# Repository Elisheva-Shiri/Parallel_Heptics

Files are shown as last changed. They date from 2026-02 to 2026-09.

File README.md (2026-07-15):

# Parallel Heptics

Hand-tracking psychophysics experiment for studying perceived stiffness through
parallel haptic feedback. A top-view camera tracks the participant's fingers,
the optional side camera remains available for side-view/z data, and an
ESP32-driven servo cluster delivers the haptic response. Participants see and
interact with a virtual object either on screen (pygame) or in VR (Unity + Meta
Quest via Quest Link).

## Components

- **Backend** (`backend.py`) — Python orchestrator. Runs vision (MediaPipe / YOLO /
  color), the virtual object simulation, the protocol/state machine, and the
  motor controller. Records video, finger trajectories, and answers per
  experiment run.
- **Frontends** — exactly one runs at a time:
  - `frontend_pygame.py` (computer screen).
  - `frontend_unity/` (Unity 6 PCVR project for Meta Quest via Quest Link).
- **Hardware** — ESP32 with PCA9685 16-channel servo driver and 15 SG92R servos
  (5 fingers × 3 servos). Firmware in `Arduino/servo_pca9685_motors_controller/`.
- **ESP32 serial bridge** (`esp32_serial_bridge/`) — required C++ UDP-to-serial
  bridge. The backend's `MotorType.HARDWARE` path only emits UDP packets to
  `HARDWARE_PORT` (12347); the bridge is what forwards them to the ESP32 over
  serial. Without it, motor commands go nowhere.
- **Moderator control** (`moderator_control.py`) — one-shot CLI for the
  moderator to toggle interaction, finish a break, or pause the run. Subjects
  can also toggle interaction from the active frontend: press Space in pygame,
  or press a Quest controller button in Unity (excluding the Meta/system button).

The data path is:

```
Cameras → backend.py → motor commands → (UDP 12347) → esp32_bridge.exe → Serial → ESP32 → servos
                    ↘ ExperimentPacket (UDP 12346) → pygame/Unity frontend
                    ↖ ExperimentControl (TCP 12344) ← moderator_control.py / frontend
```

---

## Minimum system requirements and complete setup checklist

The project does not enforce a CPU, RAM, or disk-space threshold in code. The
computer specifications below are therefore practical lower bounds inferred
from the 640x480 camera streams, MediaPipe/OpenCV processing, video recording,
and the selected frontend. For a new computer, prefer the recommended values
rather than purchasing exactly at the minimum.

### Computer requirements

| Configuration | CPU | RAM | GPU | Free storage | Operating system |
| --- | --- | --- | --- | --- | --- |
| Minimum pygame + MediaPipe | 4-core Intel Core i5 / AMD Ryzen 5 class | 8 GB | Integrated graphics are acceptable | 10 GB plus experiment recordings | Windows 10/11 64-bit |
| Recommended non-VR experiment PC | Modern 6-core CPU | 16 GB | Integrated or entry-level discrete GPU | 20-50 GB | Windows 11 64-bit |
| Quest Link / PCVR | Intel Core i7 / AMD Ryzen 7 class | 16 GB | NVIDIA RTX 20-series or AMD RX 6000-series class | 30-50 GB | Windows 10/11 64-bit |
| Unity development | Modern Core i7 / Ryzen 7 | 16 GB minimum; 32 GB preferred | RTX 20-series or newer | 50 GB or more | Windows 11 64-bit |

Before purchasing a VR computer, verify it against Meta's current
[Windows PC requirements for Meta Horizon Link](https://www.meta.com/help/quest/articles/headsets-and-accessories/oculus-link/requirements-quest-link/).

Required computer connections:

- Two USB ports for the minimum physical setup: top camera + ESP32.
- A third USB port when the optional side camera is enabled.
- An additional USB 3 port and data-capable Link cable for wired Quest Link.
- A monitor, keyboard, and mouse. An audio output is needed when white-noise
  masking is enabled.

### Hardware requirements

The minimum visual demonstration needs only the computer, one top camera, and
the pygame frontend. It does not need the ESP32, servos, side camera, or Quest.
For an intentional software-only run, set `MOTOR_TYPE = MotorType.NONE` in
`backend.py`; the committed default is `MotorType.HARDWARE`.

The minimum physical haptic system consists of:

- One ESP32 development board.
- One PCA9685 16-channel PWM/servo driver.
- Three SG92R servos for one finger cluster. The complete five-finger system
  uses 15 servos (five clusters x three servos).
- One data-capable USB cable for the ESP32.
- A separate regulated 5-6 V servo power supply, wiring, and a common ground
  shared by the supply, PCA9685, and ESP32.
- One fixed top-view USB camera. The side-view USB camera is optional.

The firmware defines 15 motors on PCA9685 channels 0-14, ESP32 I2C pins SDA 21
and SCL 22, PCA9685 address `0x40`, 50 Hz servo PWM, and 115200-baud serial.

> **Servo power safety:** Never power all servos from the ESP32 USB connector.
> The repository does not define a power-supply rating. Size the supply for the
> measured stall current of the actual servos; approximately 5 V / 10 A or more
> is a sensible engineering provision for 15 SG92R-class servos. Add suitable
> fusing or an emergency disconnect. See Adafruit's
> [PCA9685 power and library guide](https://learn.adafruit.com/16-channel-pwm-servo-driver/using-the-adafruit-library).

Optional VR hardware:

- A Meta Quest headset supported by Meta Horizon Link and its controllers.
- A high-quality USB 3 Link cable. Wired Link is preferred over Air Link for
  repeatable experiment latency.
- A Meta account and a supported dedicated GPU.

### Vision requirements and limitations

The top camera is mandatory. The backend raises an error if camera index `0`
cannot be opened. The side camera uses index `1` and can be disabled with
`--side-camera-disabled`; failure to open it does not stop the experiment.

Both cameras request:

- 640x480 capture resolution.
- 30 frames per second.
- MJPEG capture through the Windows DirectShow backend.

Use a fixed camera mount, stable and even lighting, minimal reflections and
motion blur, and a field of view that contains the complete hand and working
area. If Windows enumerates the cameras in the opposite order, exchange their
USB ports or update `TOP_CAMERA` and `SIDE_CAMERA` in `backend.py`.

Vision mode limitations:

- **MediaPipe (default and minimum recommended):** CPU operation is sufficient,
  no colored markers are needed, and the current configuration tracks one hand
  with detection confidence `0.7` and tracking confidence `0.5`.
- **Color tracking:** requires visible, distinct markers selected from red,
  green, blue, yellow, and magenta. Lighting and background color directly
  affect reliability.
- **YOLO:** uses `vision/yolo/model/best.pt` through Ultralytics. A GPU improves
  performance but is not required by the Python code.
- **Optical color GPU:** uses CUDA only when the installed OpenCV build exposes
  a CUDA device; otherwise it falls back to CPU. The normal `opencv-python`
  package should not be assumed to include CUDA support.

### Software downloads

#### Required for every experiment computer

1. **Windows 10/11 64-bit.** The current implementation uses DirectShow,
   Windows COM ports, Windows batch launchers, and a Windows serial bridge.
2. **This repository.** Copy the complete project folder or obtain it with Git
   or a ZIP download. Git is optional once the full directory is present.
3. **[uv](https://docs.astral.sh/uv/getting-started/installation/).** uv is
   mandatory and manages both Python and the virtual environment:

   ```powershell
   winget install --id=astral-sh.uv -e
   uv python install 3.12
   uv sync
   ```

   A separate Python download is not required. Although `pyproject.toml` allows
   Python 3.12 or newer, use Python 3.12 for the tested MediaPipe configuration.
   `uv sync` installs the locked runtime packages, including MediaPipe,
   OpenCV, Pydantic, pygame, pyserial, keyboard, Ultralytics, yappi, snakeviz,
   and Typer. Do not install them individually unless troubleshooting.

#### Required to flash a new ESP32

4. **[Arduino IDE 2](https://www.arduino.cc/en/software).** Select the
   **ESP32 Dev Module** board.
5. **ESP32 Arduino core.** Add the following stable Board Manager URL, install
   `esp32 by Espressif Systems`, and restart Arduino IDE. See the
   [official Espressif installation guide](https://docs.espressif.com/projects/arduino-esp32/en/latest/installing.html).

   ```text
   https://espressif.github.io/arduino-esp32/package_esp32_index.json
   ```

6. **Adafruit PWM Servo Driver library.** Install it through Arduino IDE's
   Library Manager, including any dependencies it requests.
7. **USB-serial driver, only if needed.** Install the CP210x or CH340/CH341
   Windows driver appropriate to the ESP32 board if `uv run list_ports.py`
   does not show a COM port.

#### Required for the physical haptic system

8. **ESP32 serial bridge.** The prebuilt
   `esp32_serial_bridge/esp32_bridge.exe` is committed to the repository, so no
   compiler is needed for normal runs. It receives UDP on port `12347` and
   forwards commands to the ESP32 at 115200 baud.
9. **C++ compiler, only when rebuilding the bridge.** Install either
   [MSYS2/MinGW-w64](https://www.msys2.org/) or
   [Visual Studio Build Tools](https://visualstudio.microsoft.com/downloads/)
   with the *Desktop development with C++* workload. Do not install both unless
   they are needed for unrelated development.

#### Required only for Quest/VR sessions

10. **[Meta Horizon Link](https://www.meta.com/quest/setup/)**, previously
    called Meta Quest Link. Sign in, connect the headset, set Meta Horizon Link
    as the active OpenXR runtime, and enable passthrough-over-Link when needed
    for calibration.
11. **Current NVIDIA or AMD graphics driver** from the GPU manufacturer.

The prebuilt `frontend_unity/Build/ParallelHeptics.exe` does not require Unity
Hub, the Unity Editor, or Node.js on the experiment computer.

#### Required only for editing or rebuilding Unity

12. **[Unity Hub](https://unity.com/download).** Install the exact editor
    version **Unity 6000.4.4f1**, using the
    [Unity download archive](https://unity.com/releases/editor/archive) if it
    is not shown in Hub. Windows Build Support is required; Android Build
    Support is not required because this is a Windows PCVR build, not a
    standalone Quest APK.
13. **[Node.js LTS with npm](https://nodejs.org/en/download).** It is needed
    when opening the Unity project because the MCP Unity package starts a local
    Node server:

    ```powershell
    winget install --id OpenJS.NodeJS.LTS -e
    node --version
    npm --version
    ```

Unity restores the pinned OpenXR, Meta OpenXR, Input System, Universal Render
Pipeline, and MCP Unity packages automatically from `Packages/manifest.json`.
Do not download those packages separately.

### Minimum startup sequence

```powershell
# One-time Python environment setup
uv python install 3.12
uv sync

# Find the ESP32 port
uv run list_ports.py

# Start the physical motor bridge; replace COM13 with the detected port
esp32_serial_bridge\esp32_bridge.exe COM13

# Start the backend
uv run backend.py

# Start exactly one frontend: pygame...
uv run frontend_pygame.py
```

For VR, start Meta Horizon Link, connect the Quest, and launch
`frontend_unity/Build/ParallelHeptics.exe` instead of pygame. Only one frontend
may run because pygame and Unity both bind UDP port `12346`. The backend control
server uses TCP port `12344`, and the motor bridge uses UDP port `12347`.

---

## Running the experiment

These steps are everything needed on a fresh experiment computer. Most of the
heavy configuration is committed to the repo so it does not need to be redone.

### 1. Install prerequisites

- **Python via uv** — install [uv](https://docs.astral.sh/uv/getting-started/installation/),
  then from the repo root:
  ```bash
  uv python install 3.12
  uv sync
  ```
  `uv sync` reads `pyproject.toml` / `uv.lock` and creates `.venv` with all
  dependencies pinned.

- **Meta Quest Link app** — install from
  [meta.com/quest/setup](https://www.meta.com/quest/setup/). Required for PCVR;
  not needed if you only use the pygame frontend.

- **Unity Hub + Unity 6000.4.4f1** — only required if the Unity scene needs to be
  rebuilt. For day-to-day experiment runs, use the prebuilt Windows player at
  `frontend_unity/Build/ParallelHeptics.exe` (see step 5).

- **Node.js / npm** — required when opening the Unity project because the MCP
  Unity package builds a small local server. Install Node.js LTS, then enable
  npm in PowerShell if Windows blocks it:
  ```powershell
  winget install --id OpenJS.NodeJS.LTS -e --source winget
  Set-ExecutionPolicy -Scope CurrentUser -ExecutionPolicy RemoteSigned
  npm -v
  ```

### 2. Plug in hardware and find the COM port

1. Connect the ESP32 with a **data** USB cable (not charge-only).
2. Connect the two USB cameras (top and side).
3. List serial ports:
   ```bash
   uv run list_ports.py
   ```
   Note the COM port flagged as a likely ESP32 (e.g. `COM13`).

The first time on a new computer you may need the CP210x or CH340 USB-serial
driver — `list_ports.py` warns when no port shows up.

### 3. Flash the ESP32 (only once per board)

The ESP32 firmware is pre-calibrated and pinned in
`Arduino/servo_pca9685_motors_controller/esp32_servo_pca9685.ino`. Flash from
Arduino IDE with the **ESP32 Dev Module** board selected. Required libraries:
`Adafruit PWM Servo Driver`. Servo min/max ticks are baked into the sketch
constants, so no per-board calibration is needed.

A flashed ESP32 can be moved between computers without re-flashing.

### 4. Generate the experiment configuration

`configuration.csv` defines the stiffness pairs the protocol will run. Re-run
this only if you want to change comparisons / standard / amounts:

```bash
uv run configuration.py
```

Per-participant protocols already live as top-level CSV files in `protocols/`.
The backend can prompt for one at startup or accept it with `--protocol`; nested
folders such as `protocols/detailed/` are ignored by the selector.

### 5. Start the ESP32 serial bridge

Use the prebuilt `esp32_serial_bridge/esp32_bridge.exe`:

```bash
esp32_serial_bridge\esp32_bridge.exe COM13
```

Replace `COM13` with the port from step 2. If `esp32_bridge.exe` is missing,
build it once with `esp32_serial_bridge\build.bat` (MinGW) or `build_msvc.bat`
(Visual Studio); see [Development setup](#development-setup) for compiler
install.

### 6. Start the backend

The backend owns the TCP control socket that the frontend and
`moderator_control.py` connect to, so it must be running before any frontend.

```bash
uv run backend.py
```

The backend prompts interactively for protocol, run mode, motor set, vision
type, optional side camera, white noise, hand mirroring, and target cycle count. Any
answer can also be passed as a flag — see `uv run backend.py --help`. For
example, choose a protocol directly with:

```bash
uv run backend.py --protocol participant_1
```

Per-run output
(video, finger CSVs, answers) lands in `live_experiments/<timestamp>_…/` (or
`debug_experiments/` when `IS_DEBUG = True`).

### 7. Start the frontend

Pick one. The same backend port (`12346`) serves both, so the choice is just
which app you launch.

- **Pygame (computer screen):**
  ```bash
  run_pygame.bat
  ```
  or `uv run frontend_pygame.py`.

- **Unity / Quest VR:**
  1. Put on the headset, plug into the PC, and open the **Meta Quest Link**
     desktop app.
  2. Set Meta Quest Link as the active OpenXR runtime (Meta Quest Link app →
     *Settings → General → OpenXR Runtime → Set Meta Quest Link*).
  3. Enable passthrough during calibration - In the Meta Quest Link app *Settings → Beta*, enable *Passthrough over Meta
  Quest Link*
  4. Press the **Quest Link** button inside the headset to connect.
  5. Launch `frontend_unity/Build/ParallelHeptics.exe`.

  If the build is missing, open `frontend_unity/frontend_unity` in Unity Hub
  with version `6000.4.4f1`, open `Assets/Scenes/FrontendUnity.unity`, run
  *Parallel Heptics → Configure OpenXR for Quest Link* once, then *File → Build
  And Run* to regenerate the Windows player. The XR loader, OpenXR, and Meta
  passthrough packages are already pinned in the project's `Packages/manifest.json`.

  Tabletop calibration is per-computer but persists in Unity `PlayerPrefs`
  after the first run — see `frontend_unity/frontend_unity/Assets/README_FrontendUnity.md`
  for the calibration keybindings. The calibration view uses passthrough to
  show the real table behind the virtual surface; for that step (only) enable
  *Passthrough over Meta Quest Link* in the Meta Quest Link app's *Settings →
  Beta*. Once calibration is saved, the experiment runs without passthrough
  and the beta toggle is no longer needed.

### 8. Moderator commands during a run

From any terminal in the repo root, run **one** at a time:

```bash
uv run moderator_control.py --toggle-interaction   # -i, manual interaction toggle (also available via Space/Unity controller)
uv run moderator_control.py --toggle-break         # -b, finish a configured break
uv run moderator_control.py --pause                # -p, unscheduled pause; run again to resume
```

`--pause` freezes experiment progression, disables active interaction/haptics
while paused, and logs start/finish/duration to `moderator_pauses.csv`.

### 9. Stop and collect data

`Ctrl+C` in the backend terminal performs a graceful shutdown (closes video
writers, flushes CSVs, stops motors). Recorded data is in the run's output
folder under `live_experiments/`.

### What is preconfigured (do not redo)

- Python dependencies are locked in `uv.lock`.
- ESP32 firmware constants (servo min/max ticks, channel mapping, baud) are in
  the `.ino` file — flash once per board.
- Per-participant protocol CSVs are committed under `protocols/`.
- Unity XR / OpenXR / Meta passthrough package versions are pinned in
  `frontend_unity/frontend_unity/Packages/manifest.json`.
- Network ports (`12344`, `12346`, `12347`) are constants in `consts.py` and
  match across backend, frontends, and the bridge.

### What is per-machine (must redo on a new computer)

- Meta account login in the Meta Quest Link PC app and the Quest headset.
- Setting Meta Quest Link as the active OpenXR runtime.
- Unity tabletop calibration (saved in local `PlayerPrefs`).
- Camera indices: the backend assumes top camera = index 0, side camera = 1.
  If a new machine enumerates them in the opposite order, swap USB ports
  before changing code.

---

## Development setup

Only needed if you intend to modify code, not just run experiments.

### Python

`uv sync` from the repo root installs runtime + dev dependencies (`ipdb`,
`ipykernel`, `matplotlib`, `numpy`, `pandas`, `ruff`).

```bash
uv run ruff check        # lint
uv run pytest            # tests
```

### C++ (ESP32 serial bridge)

Install **one** of:

- **MinGW-w64** via [MSYS2](https://www.msys2.org/), then in the MSYS2 terminal:
  ```bash
  pacman -S mingw-w64-ucrt-x86_64-gcc base-devel mingw-w64-ucrt-x86_64-toolchain
  ```
  Add `C:\msys64\mingw64\bin` to PATH and verify with `g++ --version`.
- **Visual Studio** with the *Desktop development with C++* workload.

Then from a Command Prompt in `esp32_serial_bridge/`:

```bat
build.bat        :: MinGW
build_msvc.bat   :: MSVC
```

Output: `esp32_bridge.exe`. Commit the rebuilt binary if you change the bridge
sources, so other experiment computers do not need a C++ toolchain.

See `esp32_serial_bridge/README.md` for CLI flags, log format, and protocol
details.

### Arduino firmware

Open `Arduino/servo_pca9685_motors_controller/esp32_servo_pca9685.ino` in
Arduino IDE 2.x. Board: *ESP32 Dev Module*. Library: *Adafruit PWM Servo
Driver*. The `dc_motors_controller/` and `servo_basic_sketch/` folders are
older alternatives kept for reference.

### Unity

Open `frontend_unity/frontend_unity/` in Unity Hub with **Unity 6000.4.4f1**
(matching `ProjectSettings/ProjectVersion.txt`). Required packages auto-resolve
from `Packages/manifest.json`. The XR-Meta-OpenXR setup is automated by the
menu item *Parallel Heptics → Configure OpenXR for Quest Link* — run it once
after first opening the project.

For headset use:

- Set Meta Quest Link as the active OpenXR runtime in the Meta Quest PC app.
- In the Meta Quest Link app *Settings → Beta*, enable *Passthrough over Meta
  Quest Link* if you want passthrough during calibration.

### Project layout

```
backend.py                       # main orchestrator
frontend_pygame.py               # computer-screen frontend
frontend_unity/                  # Unity PCVR frontend
moderator_control.py             # moderator one-shot CLI
configuration.py                 # generates configuration.csv
consts.py                        # shared constants (ports, sizes, finger map)
structures.py                    # pydantic models for backend↔frontend packets
vision/                          # mediapipe / yolo / color vision backends
motor_controller.py              # geometry → motor command translation
haptic_mapping.py                # object displacement → tactor mapping
Arduino/                         # ESP32 / servo firmware
esp32_serial_bridge/             # optional C++ UDP→serial bridge
protocols/                       # committed per-participant protocols
analysis/                        # offline analysis notebooks/scripts
tests/                           # pytest suite
```

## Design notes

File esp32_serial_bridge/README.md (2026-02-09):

# ESP32 Serial Bridge

A high-performance C++ UDP-to-Serial bridge for ESP32 motor control. Receives motor commands via UDP and forwards them directly to the ESP32 via serial, minimizing latency compared to Python serial communication.

## Prerequisites

You need **one** of the following C++ compilers installed:

### Option 1: MinGW (Recommended for simplicity)

1. Download MinGW-w64 from: https://www.mingw-w64.org/downloads/
   - Or use MSYS2: https://www.msys2.org/

2. If using MSYS2, open MSYS2 terminal and run:
   ```bash
   pacman -S mingw-w64-x86_64-gcc
   ```

3. Add MinGW bin folder to your PATH:
   - Default MSYS2 path: `C:\msys64\mingw64\bin`
   - Verify installation: `g++ --version`

### Option 2: Visual Studio

1. Download Visual Studio from: https://visualstudio.microsoft.com/
   - Community edition is free

2. During installation, select **"Desktop development with C++"** workload

3. After installation, the build script will automatically find Visual Studio

## Building

Open a **Command Prompt** (not PowerShell) in this folder and run:

```batch
# Using MinGW
build.bat

# Using Visual Studio
build_msvc.bat
```

This creates `esp32_bridge.exe` in the current folder.

## Usage

```
esp32_bridge.exe <COM_PORT> [OPTIONS]

Arguments:
  COM_PORT              Serial port (e.g., COM13)

Options:
  --log-path PATH       Log file path (default: esp32_bridge_YYYYMMDD_HHMMSS.log)
  --no-log              Disable all logging (for minimum latency)
  --quiet               Disable console output (file-only logging)
  -h, --help            Show help message
```

### Examples

```batch
# Basic usage with default logging
esp32_bridge.exe COM13

# Custom log file
esp32_bridge.exe COM13 --log-path motor_log.txt

# No logging for minimum latency
esp32_bridge.exe COM13 --no-log

# Log to file only, no console output
esp32_bridge.exe COM13 --quiet
```

### Stopping

Press `Ctrl+C` to gracefully shut down the bridge.

## Integration with Python Backend

The bridge replaces direct Python-to-ESP32 serial communication with a UDP intermediary:

```
Python Backend  ---(UDP:12347)--->  ESP32 Bridge  ---(Serial)--->  ESP32
```

### Setup

1. Start the bridge first:
   ```batch
   esp32_bridge.exe COM13
   ```

2. In `backend.py`, change line 46:
   ```python
   MOTOR_TYPE = MotorType.TECHNOSOFT  # Was: MotorType.ARDUINO
   ```

3. Run the Python backend normally - it will send UDP packets to port 12347, which the bridge forwards to serial.

## Protocol

### Message Format

Motor commands use ASCII format: `ZM<index>P<position>...F`

Examples:
- `ZM0P500F` - Move motor 0 to position 500
- `ZM0P100M1P-50M2P200F` - Move motors 0, 1, 2 simultaneously

### Communication

- **UDP Port:** 12347 (matches `TECHNOSOFT_PORT` in `consts.py`)
- **Serial:** 115200 baud, 8N1, no flow control
- **DTR/RTS:** Disabled to prevent ESP32 reset on connection

## Log Format

```
[2026-01-25 12:34:56.789] [UDP IN    ] ZM0P500M1P-200F
[2026-01-25 12:34:56.790] [SERIAL OUT] ZM0P500M1P-200F
[2026-01-25 12:34:56.823] [SERIAL IN ] OK:M0P500,M1P-200
```

## Architecture

```
┌─────────────────┐
│   Main Thread   │  Initialization, signal handling, cleanup
└────────┬────────┘
         │
    ┌────┴────┐
    │         │
┌───▼───┐ ┌───▼───┐
│Writer │ │Reader │
│Thread │ │Thread │
└───┬───┘ └───┬───┘
    │         │
    │  UDP    │  Serial
    │  recv   │  read
    │    │    │    │
    │    ▼    │    ▼
    │ Serial  │  Logger
    │  write  │
    └────┬────┘
         │
    ┌────▼────┐
    │  ESP32  │
    └─────────┘
```

## Troubleshooting

### "g++ not found"
- Install MinGW and add to PATH (see Prerequisites)
- Or use `build_msvc.bat` with Visual Studio instead

### "Failed to open COM port"
- Check the port name (use Device Manager to find correct COM port)
- Ensure no other program is using the port
- Try running as Administrator

### "Failed to bind UDP socket"
- Port 12347 may be in use - check for other instances
- Firewall may be blocking - allow the program through Windows Firewall

### ESP32 resets on connection
- This shouldn't happen (DTR/RTS are disabled)
- If it does, check your USB cable and ESP32 board

## Files

```
esp32_serial_bridge/
├── src/
│   ├── main.cpp           # Entry point, threads, CLI parsing
│   ├── serial_port.hpp    # Serial port interface
│   ├── serial_port.cpp    # Windows COM port implementation
│   ├── udp_receiver.hpp   # UDP receiver interface
│   ├── udp_receiver.cpp   # Winsock implementation
│   ├── logger.hpp         # Logger interface
│   └── logger.cpp         # Thread-safe logging
├── build.bat              # MinGW build script
├── build_msvc.bat         # MSVC build script
└── README.md              # This file
```

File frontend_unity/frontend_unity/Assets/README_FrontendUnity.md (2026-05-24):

# Frontend Unity

Efficient Unity PCVR frontend for the Parallel Heptics backend.

## Switching between pygame and Unity

Both pygame and Unity use the same backend protocol:

- UDP `ExperimentPacket` from backend to frontend on port `12346`
- TCP `ExperimentControl` from frontend to backend on port `12344`

Run exactly one frontend at a time:

1. Pygame: run `run_pygame.bat` / `frontend_pygame.py`.
2. Unity: open this project, open `Assets/Scenes/FrontendUnity.unity`, press Play, and use Quest Link for PCVR.

Unity listens on the pygame port (`12346`) by default so it can replace pygame without a backend architecture change.

Both frontends can play a low-volume looping white-noise mask, but the baseline/default is no white noise:

- When starting `backend.py`, answer `y` to `Apply white noise? [y/N]:` to enable it for the active frontend.
- Press Enter or answer `n` to keep the default no-noise baseline.
- Pygame plays the mask through the computer audio device.
- Unity generates the mask procedurally in the Unity scene, so PCVR/headset audio follows Unity's output device.

## Moderator controls

Unity renders experiment state but does not own moderator keyboard shortcuts.
Use the Python moderator utility from the repository root:

```bash
uv run moderator_control.py --toggle-interaction   # or --toggle_interaction / -i; manual interaction mode
uv run moderator_control.py --toggle-break   # or -b, finishes a configured break
uv run moderator_control.py --pause          # or -p, run again to resume
```

The `--pause` command is an unscheduled moderator pause. The backend pauses
experiment progression, disables active interaction/haptics while paused, and logs
start/finish/duration to `moderator_pauses.csv`.

## Unity frontend design

- Receives UDP on a background thread.
- Stores only the latest packet; old packets are dropped to avoid visual latency/backlog.
- Parses one latest JSON packet per Unity frame.
- Reuses scene objects/materials; no per-frame instantiate/destroy.
- Uses backend-provided landmarks for left/right hold-to-answer behavior.
- Renders the experiment as a world-locked horizontal tabletop surface rather than a head-locked display.
- Defaults to a large 2 m × 2 m tabletop visualization area so the experiment is readable in the headset. The backend coordinate system is still normalized and unchanged.

## Tabletop calibration

The first calibration implementation is intentionally simple and local to Unity. It does not change the Python backend or pygame.

In Unity Play Mode, align the virtual 20 cm surface to the real table area:

- Arrow keys: slide the surface across the table plane.
- Shift + arrow keys: slide faster.
- PageUp / PageDown: raise/lower the surface height.
- Q / E: yaw-rotate the surface on the table.
- Hold `[` / `]`: shrink/grow the surface uniformly.
- Click `[` / `]`: shrink/grow in small steps.
- Enter: save calibration to local Unity `PlayerPrefs` and stop calibration movement.
- R: restart calibration movement after it has been saved/locked.

During calibration, the black panel becomes nearly transparent and AR Foundation passthrough is enabled so the real table is visible behind the virtual working area. Pressing Enter saves the calibration, disables calibration movement, restores the opaque black experiment surface, and turns passthrough off.

After saving, the tabletop transform reloads on the next Play Mode run and starts locked. The surface is a root-level world object, not a child of the XR Origin/camera, so moving the headset should change the viewpoint but should not drag the experiment area with the head.

Limit: Quest/OpenXR tracking can still shift if the runtime loses tracking or recenters. This first pass does not use spatial anchors or camera/fiducial tracking; those can be added later if the physical alignment needs persistence across runtime recentering or sessions.

## Quest Link / OpenXR notes

For headset use, set Meta Quest Link as the active OpenXR runtime in the Meta Quest PC app, then run this Unity project in Play Mode or as a Windows build.

The project includes Unity's Meta OpenXR package and the menu item `Parallel Heptics > Configure OpenXR for Quest Link` enables the Standalone OpenXR loader plus Meta Quest passthrough features. Quest Link passthrough also requires Meta's PC runtime to allow passthrough over Link; in the Meta Quest Link app, enable the beta/developer runtime passthrough option if it is not already enabled.

## Headset image quality and delay checklist

This frontend is a **PCVR / Quest Link** app. Do not deploy/upload it as a
standalone Android Quest build for experiments; launch the Windows player or
Unity Play Mode through Quest Link.

If the headset view becomes blocky, wavy, or delayed:

1. Run `Parallel Heptics > Configure OpenXR for Quest Link` after opening the
   project. It keeps the Standalone OpenXR loader, Meta controller/passthrough
   features, and Quest latency option configured.
2. Start only one frontend at a time. If pygame and Unity both listen on UDP
   `12346`, stop pygame before running Unity.
3. Prefer a USB 3 Link cable/port for the experiment. Air Link or a weak USB
   connection can still create video-compression pixelation outside Unity's
   control.
4. Use a non-development Windows build for sessions when possible. Editor Play
   Mode is useful for calibration/debugging but has extra CPU/GPU overhead.
5. Leave passthrough only for calibration. After pressing Enter to save
   calibration, the experiment panel turns opaque and passthrough is disabled.

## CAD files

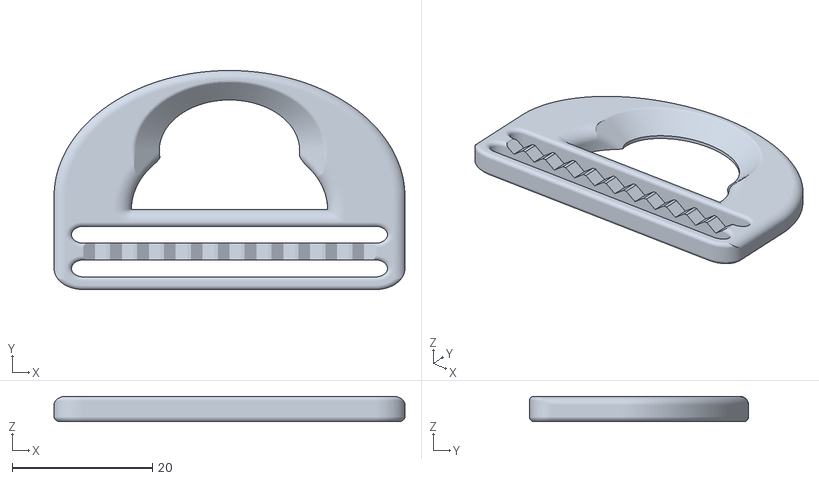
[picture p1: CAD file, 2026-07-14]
model/Belt/female.stl
50.0 x 31.2 x 3.60

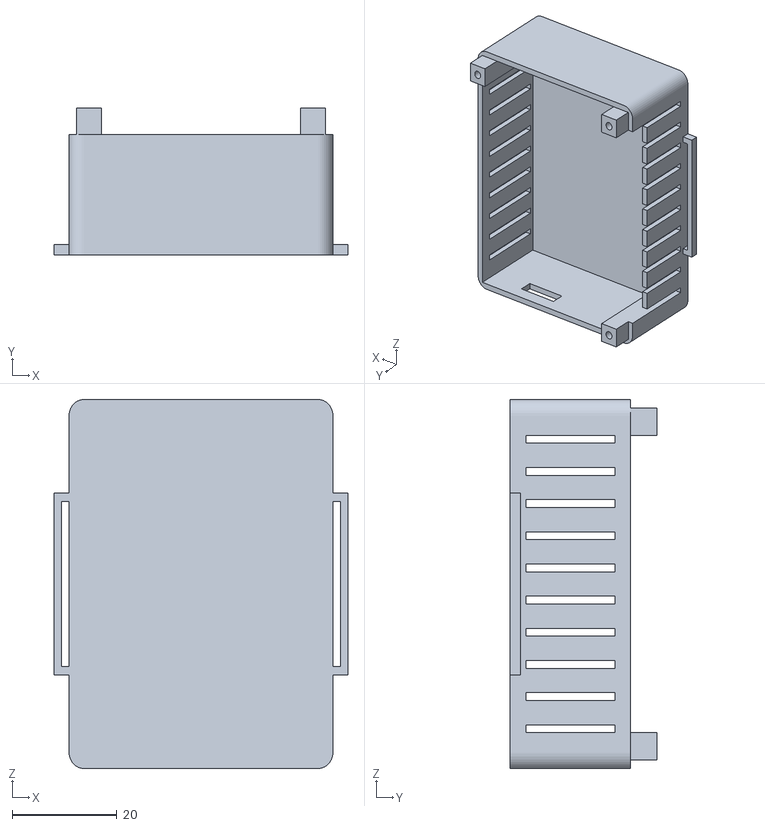
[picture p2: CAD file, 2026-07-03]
model/Electronic/Electronic_Box.STL
56.1 x 28.0 x 70.3

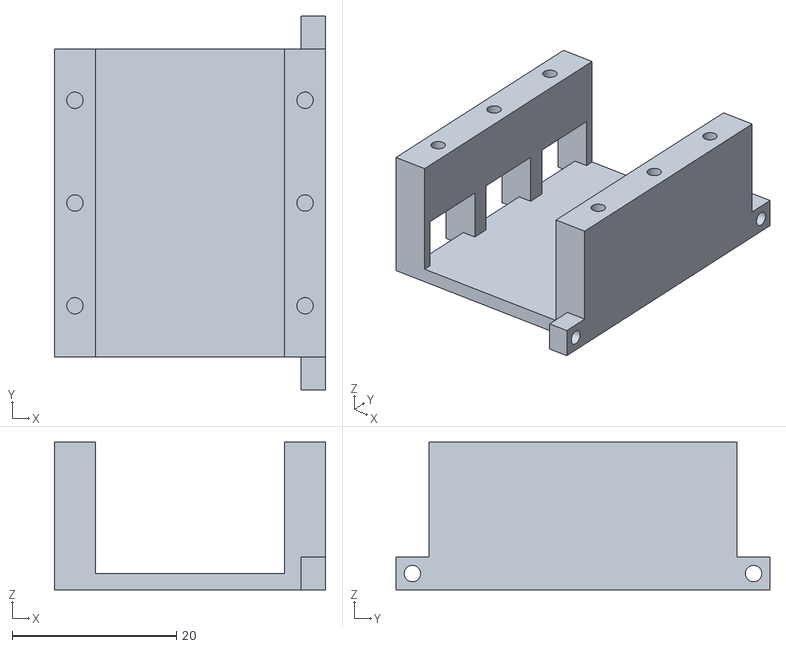
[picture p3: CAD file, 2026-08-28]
model/Motors/Motors_holder.STL
33.0 x 45.5 x 18.0

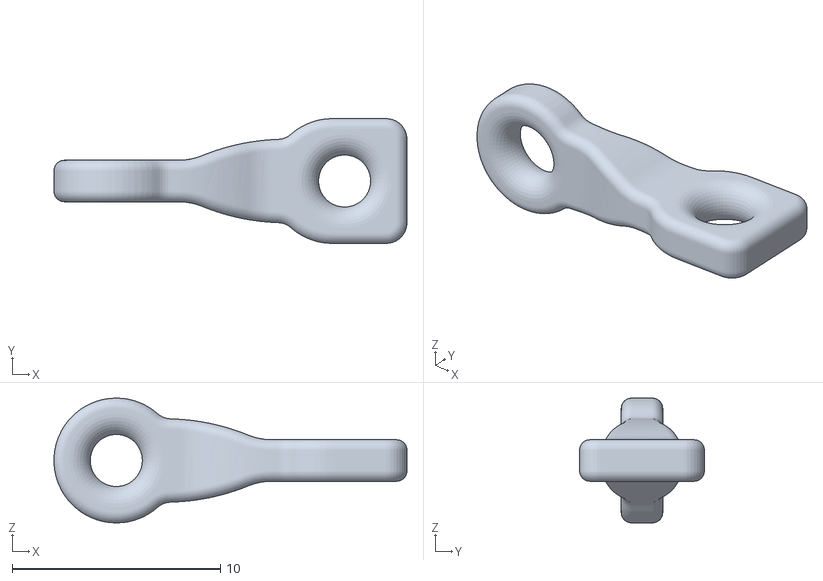
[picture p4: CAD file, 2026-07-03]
model/thimble/Thimble_Leg_1_(rr).STL
17.0 x 6.00 x 6.00

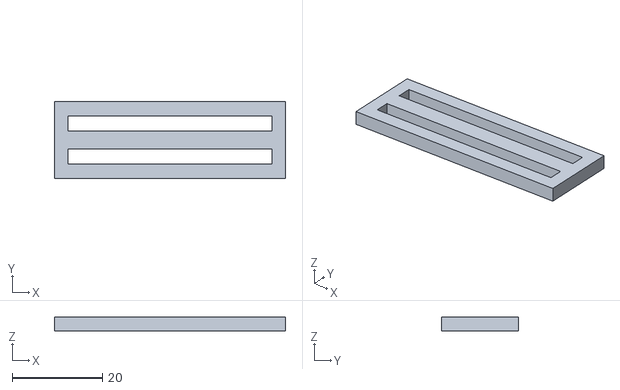
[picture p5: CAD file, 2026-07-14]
model/Belt/export.stl
51.1 x 17.0 x 3.00

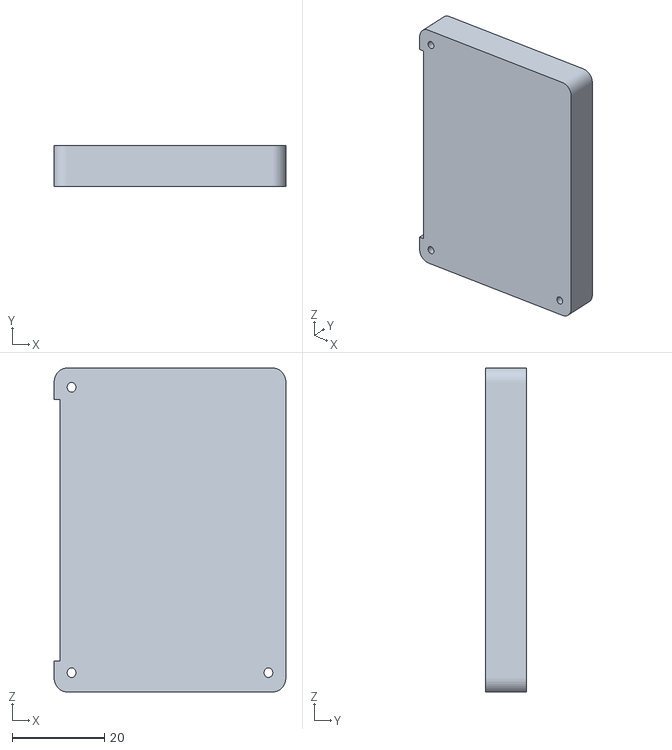
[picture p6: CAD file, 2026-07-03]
model/Electronic/Electronic_Top.STL
50.3 x 9.00 x 70.3

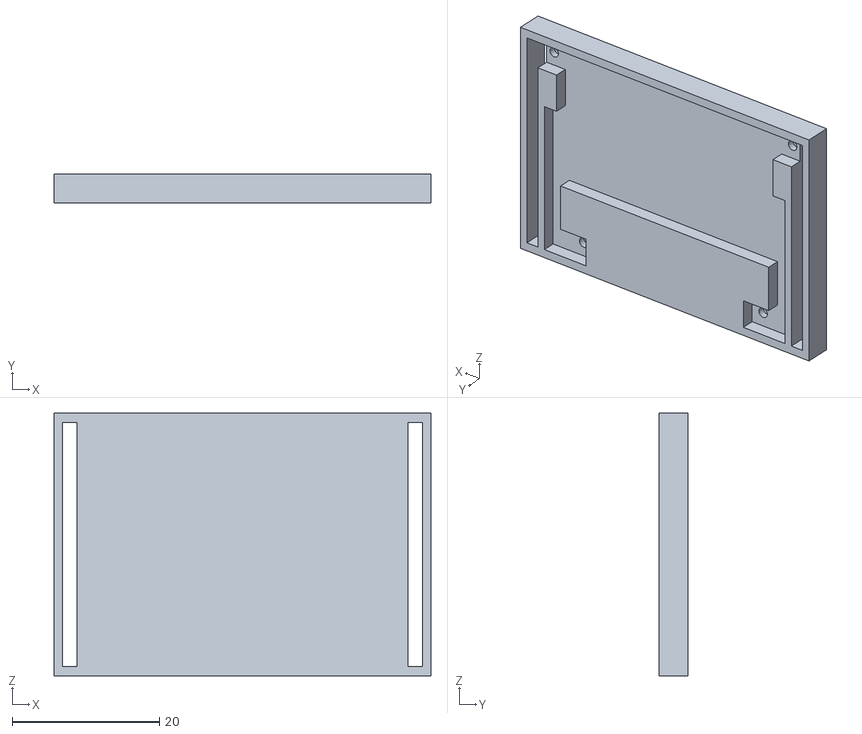
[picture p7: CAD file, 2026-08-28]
model/Motors/Motors_Base.STL
51.2 x 4.00 x 35.7

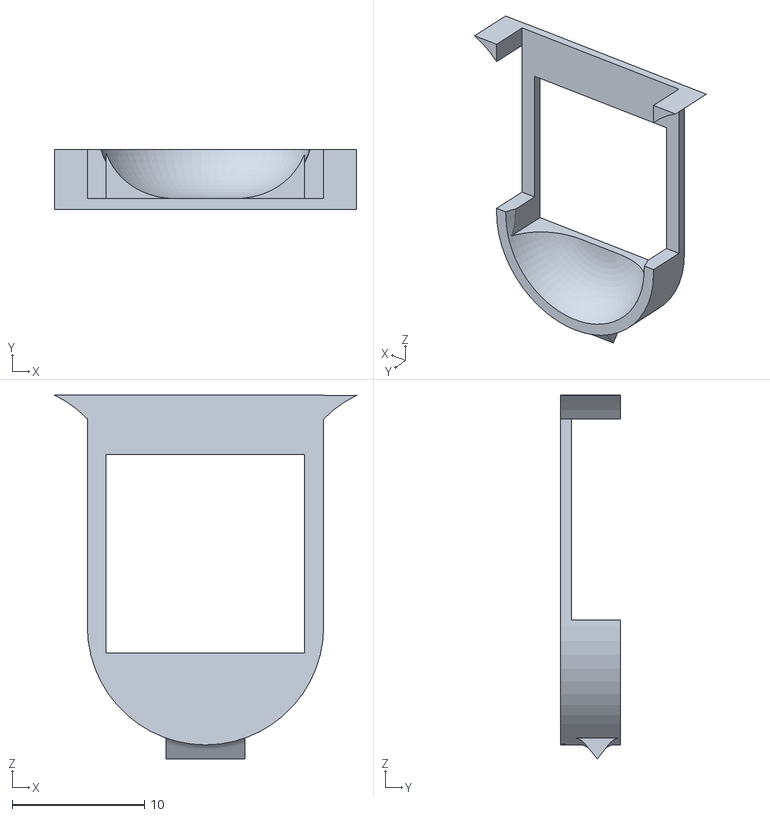
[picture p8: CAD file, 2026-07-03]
model/thimble/Thimble_Cover.STL
22.8 x 4.50 x 27.5

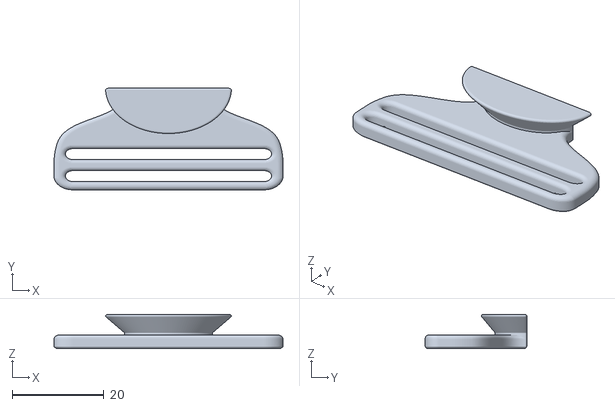
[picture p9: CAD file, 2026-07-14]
model/Belt/male.stl
50.0 x 22.2 x 7.51

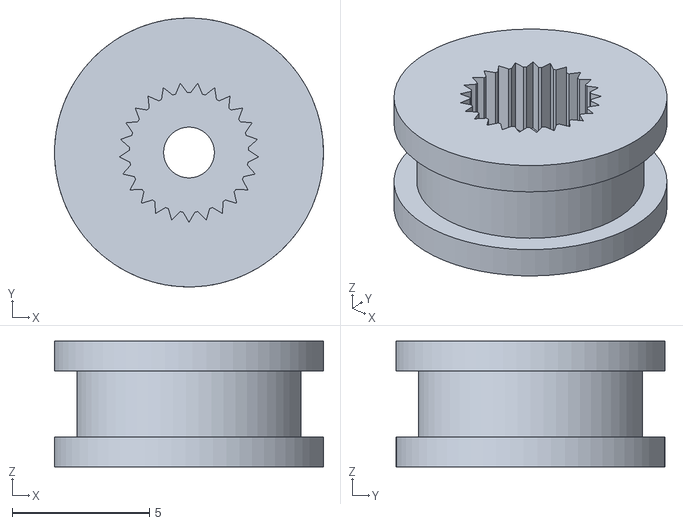
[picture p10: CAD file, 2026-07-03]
model/Motors/Motors_Spool.STL
9.81 x 9.81 x 4.58

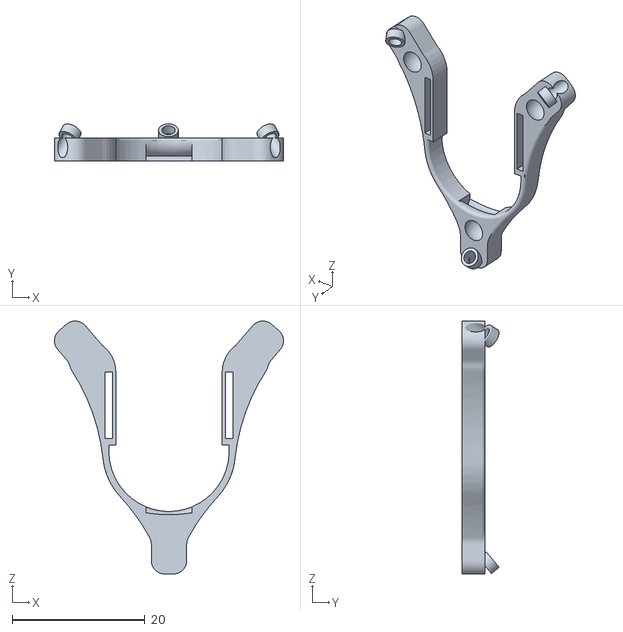
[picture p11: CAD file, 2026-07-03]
model/thimble/Thimble_Base.STL
34.5 x 5.61 x 38.1

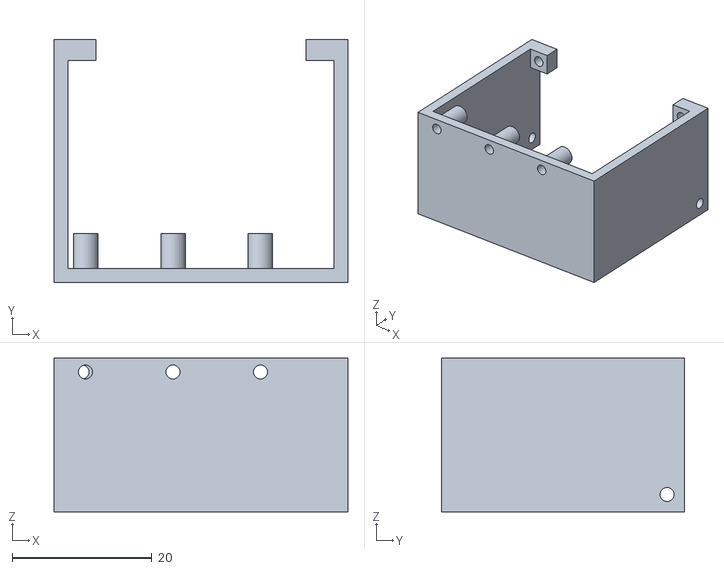
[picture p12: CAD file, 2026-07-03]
model/Motors/Motors_Sleave.STL
42.0 x 34.8 x 22.0

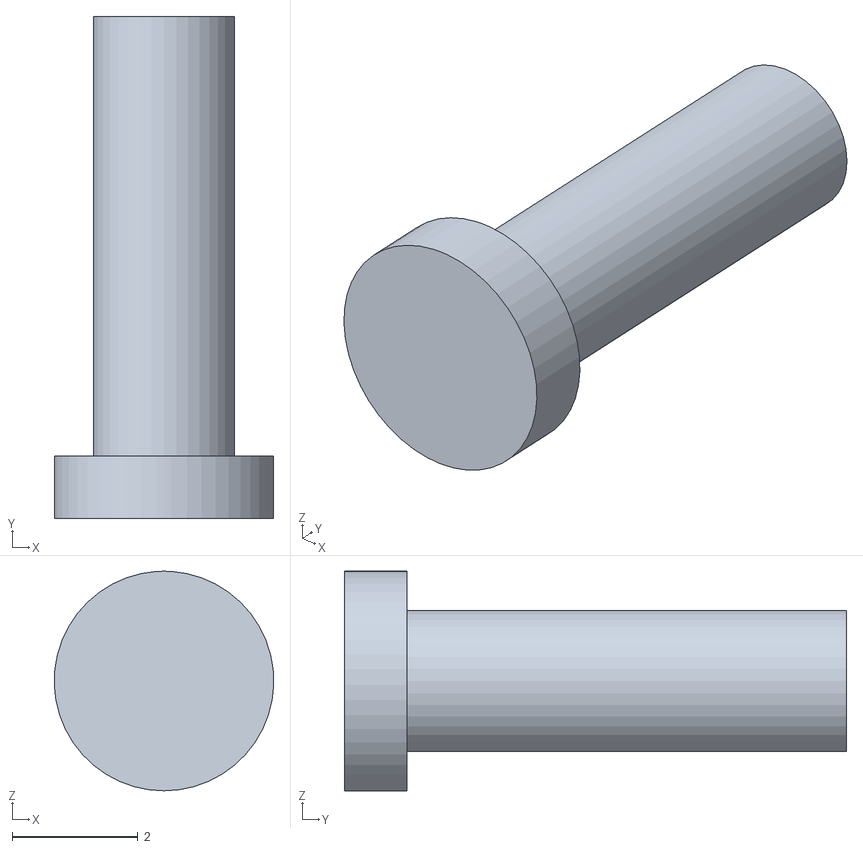
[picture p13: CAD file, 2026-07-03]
model/thimble/Thimble_Pin_2_(long).STL
3.50 x 8.00 x 3.50

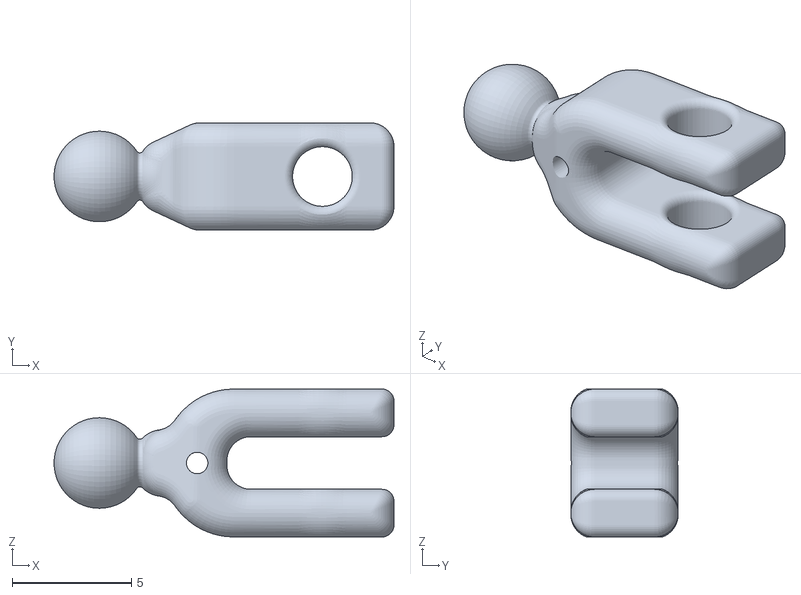
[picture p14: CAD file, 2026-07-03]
model/thimble/Thimble_Leg_2_(su).STL
14.2 x 4.50 x 6.20

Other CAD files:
model/thimble/Thimble_Pin_1_(short).STL
model/thimble/Thimble_Platform_0.STL
model/thimble/Thimble_Pin_3_(cup).STL

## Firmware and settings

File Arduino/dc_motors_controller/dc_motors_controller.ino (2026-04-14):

/**
 * ESP32 Dual-Core DC Motor Controller with Encoder Feedback
 *
 * Hardware:
 *   - ESP32
 *   - 2x TB6612FNG motor drivers
 *   - 3x PA2-50 encoders (quadrature)
 *   - 3x 64:1 gearbox with Faulhaber 0615 DC motors
 *
 * Core 0: Receives serial commands, parses them, updates command queue
 * Core 1: Executes synchronized motor movements with PID control
 *
 * Supports 1-3 motors without reflashing (auto-detects connected motors)
 *
 * Message format: "ZM<idx>P<pos>M<idx>P<pos>...F"
 * Example: "ZM0P100M1P-50M2P75F"
 */

#include "driver/pcnt.h"
#include "driver/ledc.h"
#include "Preferences.h"  // For NVS storage of PID values

// ============================================================================
// Configuration
// ============================================================================

#define NUM_MOTORS 3
#define SERIAL_BAUD 115200
#define MAX_MESSAGE_LENGTH 128
#define COMMAND_QUEUE_SIZE 10

// Encoder configuration
#define ENCODER_PPR 50           // Pulses per revolution (PA2-50)
#define QUADRATURE_MULT 4        // x4 for full quadrature decoding
#define GEAR_RATIO 64            // 64:1 gearbox
#define COUNTS_PER_REV (ENCODER_PPR * QUADRATURE_MULT * GEAR_RATIO)  // 12800

// PWM configuration
#define VMOT_VOLTAGE 5.0f        // Your VMOT supply voltage
#define MOTOR_VOLTAGE 3.0f       // Motor's rated voltage
#define MAX_PWM_DUTY (int)((MOTOR_VOLTAGE / VMOT_VOLTAGE) * 255.0f)  // = 153 for 5V VMOT
#define PWM_FREQ 20000           // 20kHz PWM frequency
#define PWM_RESOLUTION 8         // 8-bit resolution (0-255)

// PID configuration - TUNED VALUES (reduced to prevent oscillation)
#define PID_LOOP_INTERVAL_MS 5
#define DEFAULT_KP 0.5f
#define DEFAULT_KI 0.05f
#define DEFAULT_KD 0.001f
#define PID_OUTPUT_LIMIT MAX_PWM_DUTY  
#define POSITION_TOLERANCE 10    // Encoder counts tolerance for "reached position"

// Motor detection timeout
#define MOTOR_DETECT_TIMEOUT_MS 500
#define MOTOR_DETECT_PWM 50          // PWM value for detection pulse (reduced for safety)
#define MOTOR_DETECT_DURATION_MS 30  // Duration of detection pulse in ms (reduced for safety)

// Synchronized movement configuration
#define MAX_VELOCITY 5000.0f     // Maximum velocity in encoder counts per second
#define MIN_MOVEMENT_DURATION_MS 10  // Minimum movement duration in milliseconds
#define MOVEMENT_TIMEOUT_MS 7000    // Movement timeout in milliseconds

// Motion blending
#define BLEND_ENABLED true       // Enable motion blending for continuous command streams

// ============================================================================
// GPIO Pin Definitions
// ============================================================================

// Motor 1 - TB6612FNG Board #1, Channel A
#define MOTOR1_PWM   26
#define MOTOR1_IN1   27
#define MOTOR1_IN2   14
#define MOTOR1_ENC_A 19
#define MOTOR1_ENC_B 21

// Motor 2 - TB6612FNG Board #1, Channel B
// WARNING: GPIO 12 is a strapping pin! If HIGH during boot, ESP32 fails to start.
//          Ensure TB6612FNG doesn't pull this HIGH before ESP32 boots.
//          Alternative pins: 4, 5, 23 (if available)
#define MOTOR2_PWM   13
#define MOTOR2_IN1   2
#define MOTOR2_IN2   4
#define MOTOR2_ENC_A 5
#define MOTOR2_ENC_B 18

// Motor 3 - TB6612FNG Board #2, Channel A
// WARNING: GPIO 15 is a strapping pin (affects boot debug output).
//          Less critical than GPIO 12, but may cause serial garbage during boot.
//          Alternative pins: 2, 4, 5 (if available)
#define MOTOR3_PWM   25
#define MOTOR3_IN1   33
#define MOTOR3_IN2   32
#define MOTOR3_ENC_A 16
#define MOTOR3_ENC_B 17

// Pin arrays for easy iteration
const int PWM_PINS[NUM_MOTORS] = {MOTOR1_PWM, MOTOR2_PWM, MOTOR3_PWM};
const int IN1_PINS[NUM_MOTORS] = {MOTOR1_IN1, MOTOR2_IN1, MOTOR3_IN1};
const int IN2_PINS[NUM_MOTORS] = {MOTOR1_IN2, MOTOR2_IN2, MOTOR3_IN2};
const int ENC_A_PINS[NUM_MOTORS] = {MOTOR1_ENC_A, MOTOR2_ENC_A, MOTOR3_ENC_A};
const int ENC_B_PINS[NUM_MOTORS] = {MOTOR1_ENC_B, MOTOR2_ENC_B, MOTOR3_ENC_B};

// PCNT units for each encoder
const pcnt_unit_t PCNT_UNITS[NUM_MOTORS] = {PCNT_UNIT_0, PCNT_UNIT_1, PCNT_UNIT_2};

// LEDC channels for PWM
const ledc_channel_t LEDC_CHANNELS[NUM_MOTORS] = {LEDC_CHANNEL_0, LEDC_CHANNEL_1, LEDC_CHANNEL_2};

// ============================================================================
// Data Structures
// ============================================================================

struct MotorCommand {
    int motorIndex;
    int targetPosition;
};

struct CommandSet {
    MotorCommand commands[NUM_MOTORS];
    int commandCount;
    bool isValid;
};

// ============================================================================
// Forward Declarations
// ============================================================================

bool dequeueCommandSet(CommandSet* cmdSet);
void loadPIDValues();
void savePIDValues();
bool autoTunePID(int motorIdx);
void processDebugCommand(const char* cmd);

struct PIDController {
    float kp;
    float ki;
    float kd;
    float integral;
    float lastError;
    float outputLimit;
};

struct MotorState {
    volatile int32_t encoderCount;      // Current encoder position (extended beyond PCNT limit)
    volatile int32_t targetPosition;    // Target position in encoder counts
    volatile int16_t overflowCount;     // Track PCNT overflows
    PIDController pid;
    bool enabled;                        // Is this motor connected/enabled?
    bool reachedTarget;                  // Has motor reached its target?

    // Trajectory tracking for synchronized movement
    int32_t trajectoryStart;            // Start position for current trajectory
    int32_t trajectoryEnd;              // End position for current trajectory
    int32_t trajectoryDistance;         // Signed distance (end - start)

    // Stall detection
    unsigned long lastMovementTime;     // Last time encoder position changed
    int32_t lastEncoderPosition;        // Last recorded encoder position for stall detection
    int stallCount;                     // Consecutive stall detections
};

// ============================================================================
// Global Variables
// ============================================================================

MotorState motors[NUM_MOTORS];
volatile bool motorsMoving = false;
volatile int activeMotorCount = 0;

// Trajectory state for synchronized movement
struct TrajectoryState {
    unsigned long startTime;            // Movement start time in microseconds
    float duration;                     // Total movement duration in seconds
    bool active;                        // Is a trajectory currently active?
    int motorIndices[NUM_MOTORS];       // Indices of motors in this trajectory
    int motorCount;                     // Number of motors in trajectory
} trajectory;

// Command queue (protected by queueMux critical section, no volatile needed)
CommandSet commandQueue[COMMAND_QUEUE_SIZE];
int queueHead = 0;
int queueTail = 0;
portMUX_TYPE queueMux = portMUX_INITIALIZER_UNLOCKED;
portMUX_TYPE pcntMux = portMUX_INITIALIZER_UNLOCKED;

// Serial buffer
char serialBuffer[MAX_MESSAGE_LENGTH];
int bufferIndex = 0;
bool messageStarted = false;

// Task handles
TaskHandle_t serialTaskHandle;
TaskHandle_t motorTaskHandle;

// NVS storage for PID values
Preferences preferences;

// Position scaling (from backend units to encoder counts)
const float POSITION_SCALE = COUNTS_PER_REV / 1000.0;  // 1000 backend units = 1 revolution

// ============================================================================
// Serial Output Helper (sends \r\n for proper terminal display)
// ============================================================================

void serialPrintln(const char* msg) {
    Serial.print(msg);
    Serial.print("\r\n");
}

void serialPrintf(const char* format, ...) {
    char buf[256];
    va_list args;
    va_start(args, format);
    vsnprintf(buf, sizeof(buf), format, args);
    va_end(args);
    Serial.print(buf);
}

// ============================================================================
// PCNT Interrupt Handler
// ============================================================================

static void IRAM_ATTR pcntOverflowHandler(void* arg) {
    int motorIdx = (int)arg;
    uint32_t status = 0;
    pcnt_get_event_status(PCNT_UNITS[motorIdx], &status);

    portENTER_CRITICAL_ISR(&pcntMux);
    if (status & PCNT_EVT_H_LIM) {
        motors[motorIdx].overflowCount++;
    } else if (status & PCNT_EVT_L_LIM) {
        motors[motorIdx].overflowCount--;
    }
    portEXIT_CRITICAL_ISR(&pcntMux);
}


// ============================================================================
// Encoder Functions
// ============================================================================

// Flag to track if PCNT ISR service has been installed
static bool pcntIsrServiceInstalled = false;

void initEncoder(int motorIdx) {
    pcnt_config_t config = {
        .pulse_gpio_num = ENC_A_PINS[motorIdx],
        .ctrl_gpio_num = ENC_B_PINS[motorIdx],
        .lctrl_mode = PCNT_MODE_REVERSE,
        .hctrl_mode = PCNT_MODE_KEEP,
        .pos_mode = PCNT_COUNT_INC,
        .neg_mode = PCNT_COUNT_DEC,
        .counter_h_lim = 10000,
        .counter_l_lim = -10000,
        .unit = PCNT_UNITS[motorIdx],
        .channel = PCNT_CHANNEL_0,
    };
    pcnt_unit_config(&config);

    // Configure second channel for full quadrature (x4)
    config.pulse_gpio_num = ENC_B_PINS[motorIdx];
    config.ctrl_gpio_num = ENC_A_PINS[motorIdx];
    config.channel = PCNT_CHANNEL_1;
    config.pos_mode = PCNT_COUNT_DEC;
    config.neg_mode = PCNT_COUNT_INC;
    pcnt_unit_config(&config);

    // Set up overflow interrupts
    pcnt_event_enable(PCNT_UNITS[motorIdx], PCNT_EVT_H_LIM);
    pcnt_event_enable(PCNT_UNITS[motorIdx], PCNT_EVT_L_LIM);

    // Install ISR service only once (shared by all PCNT units)
    if (!pcntIsrServiceInstalled) {
        pcnt_isr_service_install(0);
        pcntIsrServiceInstalled = true;
    }
    pcnt_isr_handler_add(PCNT_UNITS[motorIdx], pcntOverflowHandler, (void*)motorIdx);

    // Enable filter to ignore glitches
    pcnt_set_filter_value(PCNT_UNITS[motorIdx], 100);
    pcnt_filter_enable(PCNT_UNITS[motorIdx]);

    // Initialize and start counter
    pcnt_counter_pause(PCNT_UNITS[motorIdx]);
    pcnt_counter_clear(PCNT_UNITS[motorIdx]);
    pcnt_counter_resume(PCNT_UNITS[motorIdx]);

    motors[motorIdx].overflowCount = 0;
}

int32_t readEncoderPosition(int motorIdx) {
    int16_t count;
    int16_t overflow;
    
    // Disable interrupts briefly to get consistent reading
    portENTER_CRITICAL_ISR(&pcntMux);
    pcnt_get_counter_value(PCNT_UNITS[motorIdx], &count);
    overflow = motors[motorIdx].overflowCount;
    portEXIT_CRITICAL_ISR(&pcntMux);
    
    return (int32_t)overflow * 10000 + count;
}

void resetEncoder(int motorIdx) {
    portENTER_CRITICAL(&pcntMux);
    pcnt_counter_pause(PCNT_UNITS[motorIdx]);
    pcnt_counter_clear(PCNT_UNITS[motorIdx]);
    motors[motorIdx].overflowCount = 0;
    motors[motorIdx].encoderCount = 0;
    pcnt_counter_resume(PCNT_UNITS[motorIdx]);
    portEXIT_CRITICAL(&pcntMux);
}

// ============================================================================
// Motor Hardware Abstraction Layer
// ============================================================================

/**
 * Initialize the motor hardware.
 * Replace this function's contents when switching motor types.
 */
void initializeMotorHardware() {
    for (int i = 0; i < NUM_MOTORS; i++) {
        // Configure direction pins
        pinMode(IN1_PINS[i], OUTPUT);
        pinMode(IN2_PINS[i], OUTPUT);
        digitalWrite(IN1_PINS[i], LOW);
        digitalWrite(IN2_PINS[i], LOW);

        // Configure PWM using LEDC
        ledc_timer_config_t timerConfig = {
            .speed_mode = LEDC_LOW_SPEED_MODE,
            .duty_resolution = (ledc_timer_bit_t)PWM_RESOLUTION,
            .timer_num = LEDC_TIMER_0,
            .freq_hz = PWM_FREQ,
            .clk_cfg = LEDC_AUTO_CLK
        };
        ledc_timer_config(&timerConfig);

        ledc_channel_config_t channelConfig = {
            .gpio_num = PWM_PINS[i],
            .speed_mode = LEDC_LOW_SPEED_MODE,
            .channel = LEDC_CHANNELS[i],
            .intr_type = LEDC_INTR_DISABLE,
            .timer_sel = LEDC_TIMER_0,
            .duty = 0,
            .hpoint = 0
        };
        ledc_channel_config(&channelConfig);

        // Initialize encoder
        initEncoder(i);

        // Initialize PID
        motors[i].pid.kp = DEFAULT_KP;
        motors[i].pid.ki = DEFAULT_KI;
        motors[i].pid.kd = DEFAULT_KD;
        motors[i].pid.integral = 0;
        motors[i].pid.lastError = 0;
        motors[i].pid.outputLimit = PID_OUTPUT_LIMIT;

        motors[i].encoderCount = 0;
        motors[i].targetPosition = 0;
        motors[i].enabled = false;
        motors[i].reachedTarget = true;

        // Initialize trajectory tracking
        motors[i].trajectoryStart = 0;
        motors[i].trajectoryEnd = 0;
        motors[i].trajectoryDistance = 0;

        // Initialize stall detection
        motors[i].lastMovementTime = 0;
        motors[i].lastEncoderPosition = 0;
        motors[i].stallCount = 0;
    }

    // Initialize trajectory state
    trajectory.active = false;
    trajectory.motorCount = 0;
}

/**
 * Set motor speed and direction.
 * This is the low-level function that interfaces with TB6612FNG.
 *
 * @param motorIndex Index of the motor (0 to NUM_MOTORS-1)
 * @param speed Speed value (-255 to 255, negative = reverse)
 */
void setMotorSpeedRaw(int motorIndex, int speed) {
    if (motorIndex < 0 || motorIndex >= NUM_MOTORS) return;
    if (!motors[motorIndex].enabled) return;

    speed = constrain(speed, -MAX_PWM_DUTY, MAX_PWM_DUTY);

    if (speed > 0) {
        // Forward
        digitalWrite(IN1_PINS[motorIndex], HIGH);
        digitalWrite(IN2_PINS[motorIndex], LOW);
        ledc_set_duty(LEDC_LOW_SPEED_MODE, LEDC_CHANNELS[motorIndex], speed);
    } else if (speed < 0) {
        // Reverse
        digitalWrite(IN1_PINS[motorIndex], LOW);
        digitalWrite(IN2_PINS[motorIndex], HIGH);
        ledc_set_duty(LEDC_LOW_SPEED_MODE, LEDC_CHANNELS[motorIndex], -speed);
    } else {
        // Stop (brake)
        digitalWrite(IN1_PINS[motorIndex], LOW);
        digitalWrite(IN2_PINS[motorIndex], LOW);
        ledc_set_duty(LEDC_LOW_SPEED_MODE, LEDC_CHANNELS[motorIndex], 0);
    }
    ledc_update_duty(LEDC_LOW_SPEED_MODE, LEDC_CHANNELS[motorIndex]);
}

/**
 * Stop a motor (coast or brake).
 */
void stopMotor(int motorIndex, bool brake = true) {
    if (motorIndex < 0 || motorIndex >= NUM_MOTORS) return;

    if (brake) {
        // Brake: both inputs HIGH
        digitalWrite(IN1_PINS[motorIndex], HIGH);
        digitalWrite(IN2_PINS[motorIndex], HIGH);
    } else {
        // Coast: both inputs LOW
        digitalWrite(IN1_PINS[motorIndex], LOW);
        digitalWrite(IN2_PINS[motorIndex], LOW);
    }
    ledc_set_duty(LEDC_LOW_SPEED_MODE, LEDC_CHANNELS[motorIndex], 0);
    ledc_update_duty(LEDC_LOW_SPEED_MODE, LEDC_CHANNELS[motorIndex]);
}

/**
 * Cleanup motor hardware.
 */
void cleanupMotorHardware() {
    for (int i = 0; i < NUM_MOTORS; i++) {
        stopMotor(i);
        pcnt_isr_handler_remove(PCNT_UNITS[i]);
    }
    pcnt_isr_service_uninstall();
}

// ============================================================================
// Motor Detection
// ============================================================================

/**
 * Detect which motors are connected by applying a brief pulse and checking encoder response.
 * After detection, each motor is returned to its original position for safety.
 */
void detectConnectedMotors() {
    serialPrintln("Detecting connected motors...");
    activeMotorCount = 0;

    for (int i = 0; i < NUM_MOTORS; i++) {
        // Reset encoder
        resetEncoder(i);

        // Apply brief forward pulse (reduced movement for safety)
        digitalWrite(IN1_PINS[i], HIGH);
        digitalWrite(IN2_PINS[i], LOW);
        ledc_set_duty(LEDC_LOW_SPEED_MODE, LEDC_CHANNELS[i], MOTOR_DETECT_PWM);
        ledc_update_duty(LEDC_LOW_SPEED_MODE, LEDC_CHANNELS[i]);

        // DEBUG
        /*
        for (int j = 0; j < 3; j++)
        {
          serialPrintf("A=%d B=%d\r\n", digitalRead(ENC_A_PINS[i]), digitalRead(ENC_B_PINS[i]));
          delay(10);
        }
        */
        delay(MOTOR_DETECT_DURATION_MS);

        // Stop motor
        stopMotor(i);

        // Check if encoder moved
        int32_t encoderDelta = readEncoderPosition(i);

        if (abs(encoderDelta) > 5) {
            motors[i].enabled = true;
            activeMotorCount++;
            serialPrintf("Motor %d: DETECTED (encoder delta: %d)\r\n", i, abs(encoderDelta));

            // Return motor to original position (position 0)
            int32_t targetPos = 0;
            unsigned long returnStart = millis();
            const unsigned long RETURN_TIMEOUT_MS = 1000;

            while (millis() - returnStart < RETURN_TIMEOUT_MS) {
                int32_t currentPos = readEncoderPosition(i);
                int32_t error = targetPos - currentPos;

                if (abs(error) <= 3) {
                    // Close enough - stop and brake
                    stopMotor(i, true);
                    break;
                }

                // Simple proportional control to return
                int pwm = constrain(error * 2, -MOTOR_DETECT_PWM, MOTOR_DETECT_PWM);
                if (pwm > 0) {
                    digitalWrite(IN1_PINS[i], HIGH);
                    digitalWrite(IN2_PINS[i], LOW);
                } else {
                    digitalWrite(IN1_PINS[i], LOW);
                    digitalWrite(IN2_PINS[i], HIGH);
                    pwm = -pwm;
                }
                ledc_set_duty(LEDC_LOW_SPEED_MODE, LEDC_CHANNELS[i], pwm);
                ledc_update_duty(LEDC_LOW_SPEED_MODE, LEDC_CHANNELS[i]);

                delay(5);
            }

            stopMotor(i, true);
            delay(50);  // Let motor settle
        } else {
            motors[i].enabled = false;
            serialPrintf("Motor %d: NOT DETECTED\r\n", i);
        }

        // Reset encoder after detection
        resetEncoder(i);
    }

    serialPrintf("Total motors detected: %d\r\n", activeMotorCount);
}

// ============================================================================
// PID Control
// ============================================================================

float computePID(int motorIdx, float error, float dt) {
    PIDController* pid = &motors[motorIdx].pid;

    // Proportional
    float pTerm = pid->kp * error;

    // Integral with anti-windup
    pid->integral += error * dt;
    pid->integral = constrain(pid->integral, -pid->outputLimit / pid->ki, pid->outputLimit / pid->ki);
    float iTerm = pid->ki * pid->integral;

    // Derivative
    float derivative = (error - pid->lastError) / dt;
    float dTerm = pid->kd * derivative;
    pid->lastError = error;

    // Combine and limit output
    float output = pTerm + iTerm + dTerm;
    return constrain(output, -pid->outputLimit, pid->outputLimit);
}

void resetPID(int motorIdx) {
    motors[motorIdx].pid.integral = 0;
    motors[motorIdx].pid.lastError = 0;
}

// ============================================================================
// Logical Motor Control Layer
// ============================================================================

/**
 * Set target position for a motor.
 *
 * @param motorIndex Index of the motor
 * @param position Target position in backend units
 */
void setMotorTargetPosition(int motorIndex, int position) {
    if (motorIndex < 0 || motorIndex >= NUM_MOTORS) return;
    if (!motors[motorIndex].enabled) return;

    // Convert backend position to encoder counts
    motors[motorIndex].targetPosition = (int32_t)(position * POSITION_SCALE);
    motors[motorIndex].reachedTarget = false;
    resetPID(motorIndex);
}

/**
 * Update a single motor's PID control loop.
 * Returns true if motor has reached target position.
 */
bool updateMotorPID(int motorIndex, float dt) {
    if (motorIndex < 0 || motorIndex >= NUM_MOTORS) return true;
    if (!motors[motorIndex].enabled) return true;
    if (motors[motorIndex].reachedTarget) return true;

    // Read current position
    motors[motorIndex].encoderCount = readEncoderPosition(motorIndex);

    // Calculate error
    float error = motors[motorIndex].targetPosition - motors[motorIndex].encoderCount;

    // Check if we've reached the target
    if (abs(error) <= POSITION_TOLERANCE) {
        stopMotor(motorIndex, true);
        motors[motorIndex].reachedTarget = true;
        return true;
    }

    // Compute PID output
    float output = computePID(motorIndex, error, dt);

    // Apply motor speed
    setMotorSpeedRaw(motorIndex, (int)output);

    return false;
}

/**
 * Check if there's a pending command in the queue (for motion blending).
 */
bool hasQueuedCommand() {
    portENTER_CRITICAL(&queueMux);
    bool hasCommand = (queueHead != queueTail);
    portEXIT_CRITICAL(&queueMux);
    return hasCommand;
}
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
void loop() {
    // All serial handling is now in serialTask
    // loop() is essentially idle
    vTaskDelay(100);
}

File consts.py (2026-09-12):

from typing import Literal


VIRTUAL_OBJECT_FPS = 60
FRONTEND_FPS = 60
MOTORS_COMMUNICATION_RATE = 150
TOP_WIDTH = 640
TOP_HEIGHT = 480
SIDE_WIDTH = 640
SIDE_HEIGHT = 480
TARGET_CYCLE_COUNT = 1
PAUSE_SLEEP_SECONDS = 60
CENTER_THRESHOLD = 20
EDGE_THRESHOLD = 30
MOVEMENT_AREA_SCALE = 0.5  # 1.0 = full size, 0.5 = half size, 2/3 = current working-area size
MOVE_FACTOR = 7
TAPPING_HEIGHT_RATIO = 0.3  # top 30% is inactive, bottom 70% is active
STIFFNESS_MAX = 175

BACKEND_PORT = 12344
UNITY_PORT = 12345
PYGAME_PORT = 12346
HARDWARE_PORT = 12347

# Finger IDs used by experiment configuration/protocol CSVs. The thumb is
# tracked separately for interaction geometry; configured IDs select the active
# non-thumb finger unless single-finger mode explicitly selects thumb.
FINGER_NAMES: dict[int, str] = {
    0: "index",
    1: "middle",
    2: "ring",
    3: "pinky",
    4: "thumb",
}

FingerName = Literal["thumb", "index", "middle", "ring", "pinky"]

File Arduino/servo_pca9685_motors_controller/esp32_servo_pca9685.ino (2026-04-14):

/**
 * ESP32 Dual-Core Servo Controller via PCA9685
 *
 * Hardware:
 *   - ESP32
 *   - PCA9685 16-channel 12-bit PWM/Servo driver (I2C)
 *   - 3x SG92R servo motors on PCA9685 channels 0-2
 *
 * Core 0: Receives serial commands, parses them, updates command queue
 * Core 1: Executes synchronized servo movements with easing
 *
 * Message format: "ZM<idx>P<pos>M<idx>P<pos>...F"
 * Example: "ZM0P100M1P-50M2P75F"
 *
 * Based on esp32_motor_controller with PCA9685 HAL and motion blending from v13.
 */

#include <Wire.h>
#include <Adafruit_PWMServoDriver.h>

// ============================================================================
// Configuration
// ============================================================================

#define NUM_MOTORS 15          // 5 fingers x 3 servos on PCA9685 channels 0-14
#define SERIAL_BAUD 115200
#define MAX_MESSAGE_LENGTH 256
#define COMMAND_QUEUE_SIZE 10

// PCA9685 I2C configuration
#define I2C_SDA 21
#define I2C_SCL 22
#define PCA9685_ADDRESS 0x40
#define PCA9685_FREQ 50        // 50 Hz for standard servos

// Servo channel mapping on PCA9685
const int SERVO_CHANNELS[NUM_MOTORS] = {0, 1, 2, 3, 4, 5, 6, 7, 8, 9, 10, 11, 12, 13, 14};

// Servo pulse range in PCA9685 ticks (12-bit, 4096 ticks per cycle)
// At 50 Hz (20ms period): 1 tick = 20000/4096 ≈ 4.88 µs
// SG92R typical range: 500-2400 µs → ~130-500 ticks
// Calibrate these per servo using the CAL command
int servoMinTick[NUM_MOTORS] = {130, 130, 130, 130, 130, 130, 130, 130, 130, 130, 130, 130, 130, 130, 130};
int servoMaxTick[NUM_MOTORS] = {500, 500, 500, 500, 500, 500, 500, 500, 500, 500, 500, 500, 500, 500, 500};

// Position mapping
const int POSITION_RANGE = 1000;  // Backend sends positions in range [-1000, 1000]

// Deadband: minimum tick change to actually write to PCA9685 (reduces jitter)
// Set to 2+ for SG92R jitter suppression; 1 = redundant-write filter only
#define SERVO_DEADBAND_TICKS 2

// Movement configuration
#define MOVEMENT_UPDATE_INTERVAL_MS 5   // Fast updates for smooth blending at 150 Hz
#define MOVEMENT_TIMEOUT_MS 2000        // Safety timeout for movement loop
#define BLEND_ENABLED true              // Enable motion blending for continuous command streams

// ============================================================================
// Data Structures
// ============================================================================

struct MotorCommand {
    int motorIndex;
    int targetPosition;
};

struct CommandSet {
    MotorCommand commands[NUM_MOTORS];
    int commandCount;
    bool isValid;
};

// ============================================================================
// Forward Declarations
// ============================================================================

bool dequeueCommandSet(CommandSet* cmdSet);
bool hasQueuedCommand();
void processDebugCommand(const char* cmd);

// ============================================================================
// Global Variables
// ============================================================================

// PCA9685 driver
Adafruit_PWMServoDriver pwm = Adafruit_PWMServoDriver(PCA9685_ADDRESS);

// Motor state
volatile int currentPositions[NUM_MOTORS] = {0};
volatile int targetPositions[NUM_MOTORS] = {0};
int lastWrittenTicks[NUM_MOTORS] = {0};  // Track last tick written to avoid redundant writes
volatile bool motorsMoving = false;

// Command queue (thread-safe communication between cores)
CommandSet commandQueue[COMMAND_QUEUE_SIZE];
int queueHead = 0;
int queueTail = 0;
portMUX_TYPE queueMux = portMUX_INITIALIZER_UNLOCKED;

// Serial buffer
char serialBuffer[MAX_MESSAGE_LENGTH];
int bufferIndex = 0;
bool messageStarted = false;

// Task handles
TaskHandle_t serialTaskHandle;
TaskHandle_t motorTaskHandle;

// ============================================================================
// Serial Output Helper (sends \r\n for proper terminal display)
// ============================================================================

void serialPrintln(const char* msg) {
    Serial.print(msg);
    Serial.print("\r\n");
}

void serialPrintf(const char* format, ...) {
    char buf[256];
    va_list args;
    va_start(args, format);
    vsnprintf(buf, sizeof(buf), format, args);
    va_end(args);
    Serial.print(buf);
}

// ============================================================================
// Motor Abstraction Layer (PCA9685)
// ============================================================================

/**
 * Convert a backend position to a PCA9685 tick value for a specific servo.
 */
int positionToTick(int motorIndex, int position) {
    int pos = constrain(position, -POSITION_RANGE, POSITION_RANGE);

    // Map from [-POSITION_RANGE, +POSITION_RANGE] to [servoMinTick, servoMaxTick]
    int tick = map((long)pos, (long)-POSITION_RANGE, (long)POSITION_RANGE,
                   (long)servoMinTick[motorIndex], (long)servoMaxTick[motorIndex]);
    return constrain(tick, servoMinTick[motorIndex], servoMaxTick[motorIndex]);
}

/**
 * Initialize the PCA9685 servo driver.
 */
void initializeMotorHardware() {
    Wire.begin(I2C_SDA, I2C_SCL);
    pwm.begin();
    pwm.setOscillatorFrequency(27000000);
    pwm.setPWMFreq(PCA9685_FREQ);
    delay(10);

    // Center all servos at position 0
    for (int i = 0; i < NUM_MOTORS; i++) {
        currentPositions[i] = 0;
        targetPositions[i] = 0;
        int tick = positionToTick(i, 0);
        pwm.setPWM(SERVO_CHANNELS[i], 0, tick);
        lastWrittenTicks[i] = tick;
    }
}

/**
 * Set servo to a position value via PCA9685.
 * Applies deadband to avoid jitter from redundant writes.
 *
 * @param motorIndex Index of the servo (0 to NUM_MOTORS-1)
 * @param position Position value (-POSITION_RANGE to +POSITION_RANGE)
 */
void setMotorPositionRaw(int motorIndex, int position) {
    if (motorIndex < 0 || motorIndex >= NUM_MOTORS) return;

    int tick = positionToTick(motorIndex, position);

    // Deadband: only write if tick actually changed
    if (abs(tick - lastWrittenTicks[motorIndex]) >= SERVO_DEADBAND_TICKS) {
        pwm.setPWM(SERVO_CHANNELS[motorIndex], 0, tick);
        lastWrittenTicks[motorIndex] = tick;
    }
}

/**
 * Cleanup: turn off all servo PWM outputs (servos go limp).
 */
void cleanupMotorHardware() {
    for (int i = 0; i < NUM_MOTORS; i++) {
        pwm.setPWM(SERVO_CHANNELS[i], 0, 4096);  // Full-off
    }
}

// ============================================================================
// Logical Motor Control Layer
// ============================================================================

/**
 * Move a motor to a target position.
 */
void moveMotorToPosition(int motorIndex, int position) {
    if (motorIndex < 0 || motorIndex >= NUM_MOTORS) return;

    currentPositions[motorIndex] = position;
    setMotorPositionRaw(motorIndex, position);
}
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

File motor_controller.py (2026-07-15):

import math
from dataclasses import dataclass
from enum import Enum, StrEnum
from typing import Any

from kinematics import unified_ik_starter as ik


class MotorSetId(Enum):
    """Physical 3-motor clusters on the 16-channel servo driver."""

    MOTORS_0_2 = 0
    MOTORS_3_5 = 1
    MOTORS_6_8 = 2
    MOTORS_9_11 = 3
    MOTORS_12_14 = 4

    @property
    def base_index(self) -> int:
        return self.value * 3

    @property
    def label(self) -> str:
        return f"{self.base_index}-{self.base_index + 2}"


class MovementStrategy(StrEnum):
    """Available movement-to-motor mapping strategies."""

    CARDINAL = "cardinal"
    CARDINAL_DIAGONAL = "cardinal_diagonal"
    FREE_FORM = "free_form"
    IK = "ik"


class HandOrientation(StrEnum):
    """Hand orientation relative to the controller coordinate frame."""

    NOT_MIRRORED = "not_mirrored"
    MIRRORED = "mirrored"


@dataclass
class MotorMovement:
    """Single motor command.

    Attributes:
        pos: Target position delta for the motor.
        index: Global motor index in the controller layout.
    """

    pos: int
    index: int


class MotorController:
    """Compute and format motor movements for a triangular 3-motor cluster.

    Motor clusters are selected by physical motor set (0-2, 3-5, ...), not by
    finger identity. The active tracked finger is decided by the experiment
    configuration; this class only knows which motor indices to command.
    """

    def __init__(
        self,
        movement_strategy: MovementStrategy,
        top_width: float,
        top_height: float,
        edge_threshold: float,
        motor_spacing: float = 1000.0,
        move_factor: float = 1.0,
        diagonal_threshold: float = 0.5,
        hand_orientation: HandOrientation = HandOrientation.NOT_MIRRORED,
    ):
        """Create a motor controller with geometry and movement parameters.
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

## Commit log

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2025-01-21 WIP Finger-specific logic, missing configuration generation
    [configuration.py, consts.py, hello.py]
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2025-11-02 added vision algorithms
    [configuration_og.csv]
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2026-04-26 Unity 2d bugfixed
    [configuration_og.csv]
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2026-04-30 protocol editing _ BUG fix
    [backend.py]
2026-04-30 add white noise sound
    [backend.py, frontend_pygame.py, structures.py]
2026-05-02 backend flags + circle indicators + unity white noise fix (not tested) + debug flag
    [backend.py, frontend_pygame.py, structures.py]
2026-05-02 white noise works, circles appear only when "pinched"
    [frontend_pygame.py]
2026-05-02 circles fix + text scale
    [frontend_pygame.py]
2026-05-02 Added (requires testing): - Option to pause - Option to continue prev experiment - Fix reset motor position when release - Rename pinch "interaction" - Update finger selection to motor set + camera t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
    [backend.py, consts.py, frontend_pygame.py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]
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2026-05-02 try to fix stutter bug
    [backend.py]
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2026-05-05 Update interaction to use buttons instead of side camera + change goals to dynamic object (circle border/full circle/rubber band) + QoL backend initialization
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2026-05-09 protocol update
    [order_balance_8_participant_types_combined.csv, participant_1.csv, participant_2.csv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]
2026-07-03 Make printable mechanism geometry publicly available
    Publish only the requested STL exports while keeping native SolidWorks assemblies, parts, and 3MF files out of version control.
    Constraint: Limit this release to files with the STL extension under model/.
    Rejected: Native CAD and 3MF sources | The requested public scope is STL exports only.
    Confidence: high
    Scope-risk: narrow
    Directive: Keep future commits limited to approved public export formats unless the release scope changes.
    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
    [Electronic_Box.STL, Electronic_Top.STL, Motors_Base.STL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]
2026-07-03 Make published STL filenames consistent and accurate
    Normalize the servo export extension to uppercase and remove the accidental SolidWorks suffix from the long-pin STL filename without changing either mesh.
    Constraint: Preserve STL binary contents and exclude all unrelated working-tree changes.
    Directive: Use the simple part-name plus .STL convention for future exports.
    Tested: Verified two R100 renames and matched each new file hash to its previous tracked blob.
    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
    [Motors_SG90_(servo).STL, Thimble_Pin_2_(long).STL]
2026-07-14 Update published model STL assets
    Refresh the published model geometry while preserving the user's requested STL-only commit scope.
    Constraint: User requested committing and pushing only .stl files from the model folder.
    Rejected: Including SolidWorks, analysis, protocol, and code changes | outside requested STL-only scope.
    Directive: Keep future model asset commits scoped by file type when requested.
    Tested: Verified staged diff contains only model/*.stl or model/*.STL paths before commit.
    Not-tested: Binary STL geometry was not rendered or mechanically validated.
    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
    [Electronic_Box.STL, Electronic_Top.STL, Motors_SG90_(servo).STL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]
2026-07-14 Clean repository artifacts
    Remove generated recovery files, obsolete local deletions, backup/debug artifacts, and saved notebook outputs to keep the public repository smaller.
    Constraint: User requested no .gitignore changes and asked to remove cleanup candidates from GitHub.
    Rejected: Changing ignore rules or publishing unrelated local edits | outside the requested repository cleanup scope.
    Scope-risk: moderate
    Directive: Keep generated results and recovery artifacts out of future commits.
    Tested: Verified .gitignore is unstaged, no tracked result/output folders remain in the index, Unity recovery files are removed, and tracked notebooks have zero outputs/execution co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
    [participant_5.csv, participant_6.csv, participant_7.csv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]
2026-07-15 Add movement strategy validation workflow
    Keep movement strategy validation code separate so the repository history follows the requested subject order.
    Constraint: User requested topic 12 first and asked to leave model sources, outputs, and paper/thesis material uncommitted.
    Rejected: Bundling validation outputs or unrelated analysis edits | outside this subject commit.
    Directive: Keep generated result artifacts out of validation commits.
    Tested: Verified only movement strategy validation files were staged and notebook outputs were cleared before commit.
    Not-tested: Runtime validation was not run for this commit.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
2026-07-15 Add IK optimization validation workflow
    Keep IK optimization validation scripts and notebook together as the requested validation topic 10 commit.
    Constraint: User requested separate subject commits and no result/output artifacts.
    Rejected: Including generated result folders or unrelated validation topics | outside topic 10.
    Directive: Keep optimization outputs separate from validation source files.
    Tested: Verified only IK optimization validation files were staged and notebook outputs were cleared before commit.
    Not-tested: IK optimization validation was not executed.
    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
2026-07-15 Update kinematics analysis workflow
    Keep kinematics analysis code, notebook, and tests together as the requested analysis topic 3 commit.
    Constraint: User requested separate analysis commits and no result folders on GitHub.
    Rejected: Including results_old or results_old2 parquet outputs | generated result artifacts.
    Directive: Keep kinematics result folders uncommitted unless explicitly requested as fixtures.
    Tested: Verified only kinematics analysis files were staged and notebook outputs were cleared before commit.
    Not-tested: Kinematics tests were not executed.
    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
2026-08-28 Update motor housing print geometry
    Constraint: User requested committing only Motors_holder.STL and Motors_Base.STL.
    Rejected: Including other staged or unstaged repository changes | outside requested file scope.
    Directive: Keep unrelated analysis, validation, and source changes out of this STL geometry commit.
    Tested: Verified both requested STL paths exist and were the only pathspecs passed to git commit.
    Not-tested: Geometry/print fit was not physically validated.
    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
    [Motors_Base.STL, Motors_holder.STL]
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
